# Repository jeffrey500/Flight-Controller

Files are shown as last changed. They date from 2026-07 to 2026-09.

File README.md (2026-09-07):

# PDFS Flight Controller

The purpose of this project is:
1. Create a Modular platform for future drone control projects 
2. Gain experience writing firmware for STM32 embedded systems
3. Become familiar more familiar with Altium and 4-layer PCB routing
4. Add to my goal of making the entire system of a drone (Project Drone Full Stack PDFS)

## Highlights

### [Video of Drone Flying](https://youtu.be/c6FY-opbWkY)

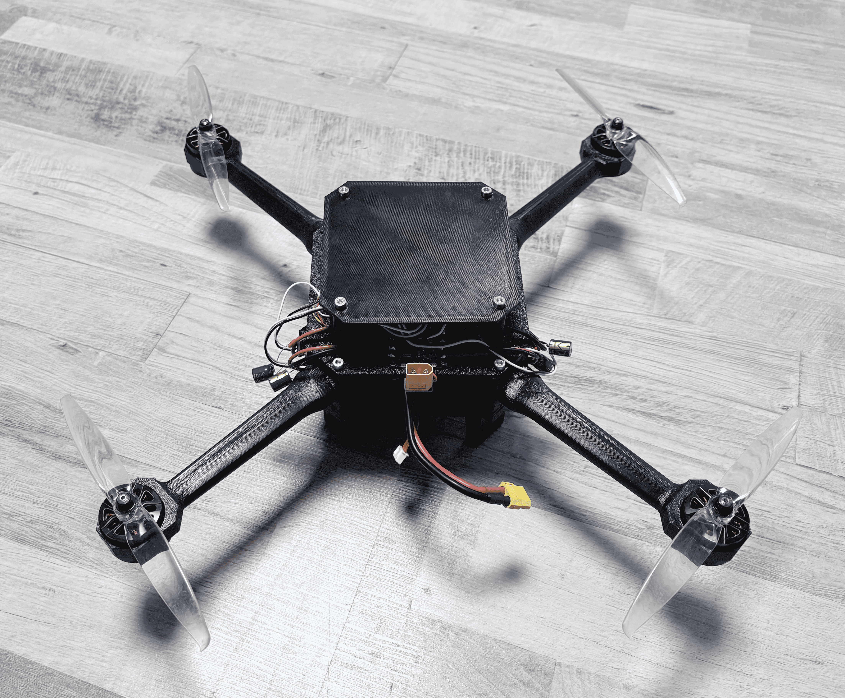
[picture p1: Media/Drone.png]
Board_front
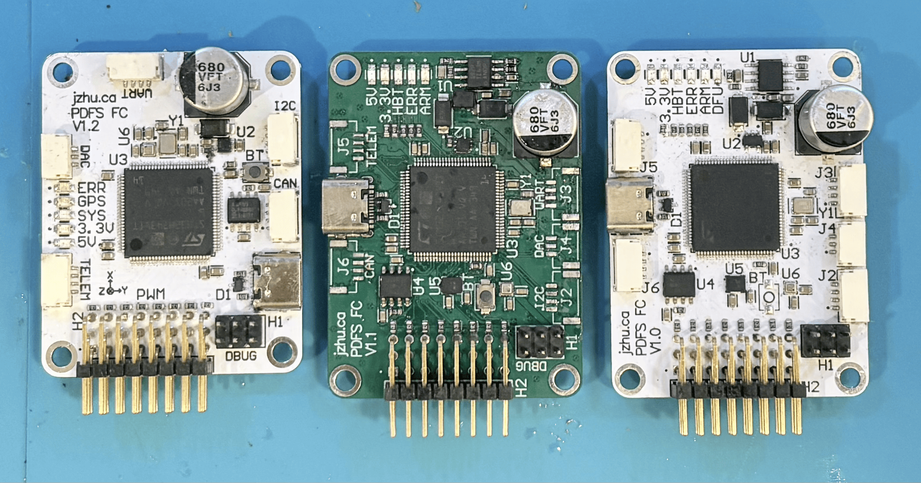
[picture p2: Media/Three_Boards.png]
Board_back
 

### [Firmware](Firmware/README.md)  

- "Angle mode" control
- Deterministic 1kHz control loop
- Cascaded PID Control
- Drivers for IMU and CRSF Radio
- Use of Direct Memory Access and Finite State Machines

### [Hardware](Hardware/README.md)

- STM32H743 Microcontroller
- 4-layer stackup + signal integrity considerations
- Integrated IMU, Barometer, Micro-SD, Buzzer, State LEDs
- Direct power from battery
- SPI, UART, I2C, CAN, USB
- 3D-Printed Drone Frame

### [Arducopter](Arducopter/README.md)

- Hardware Definitions for autonomous flight

## Future Use

Advanced control can be facilitated through connecting a flight computer to the flight controller through UART or SPI.

Altitude and position hold should be implemented in the future with the use of the integrated Barameter and external GPS + Compass.

The use of a digital camera system such as the DJI O3/O4 can be connected through the VTX video port.

## License
[Flight-Controller V1.0](https://github.com/jeffrey500/Flight-Controller) © 2026 by [Jeffrey Zhu](https://jzhu.ca) is licensed under a [Creative Commons Attribution-NonCommercial-ShareAlike 4.0 International License](https://creativecommons.org/licenses/by-nc-sa/4.0/).



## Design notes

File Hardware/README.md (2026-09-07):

# PDFS Flight Controller V1.2

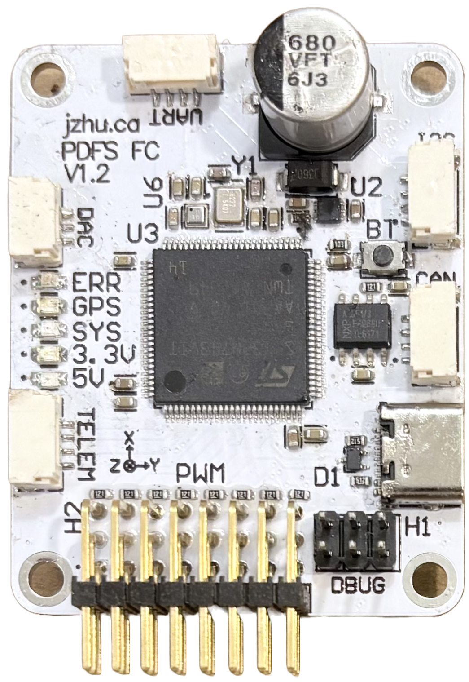
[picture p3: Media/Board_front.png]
Board_front
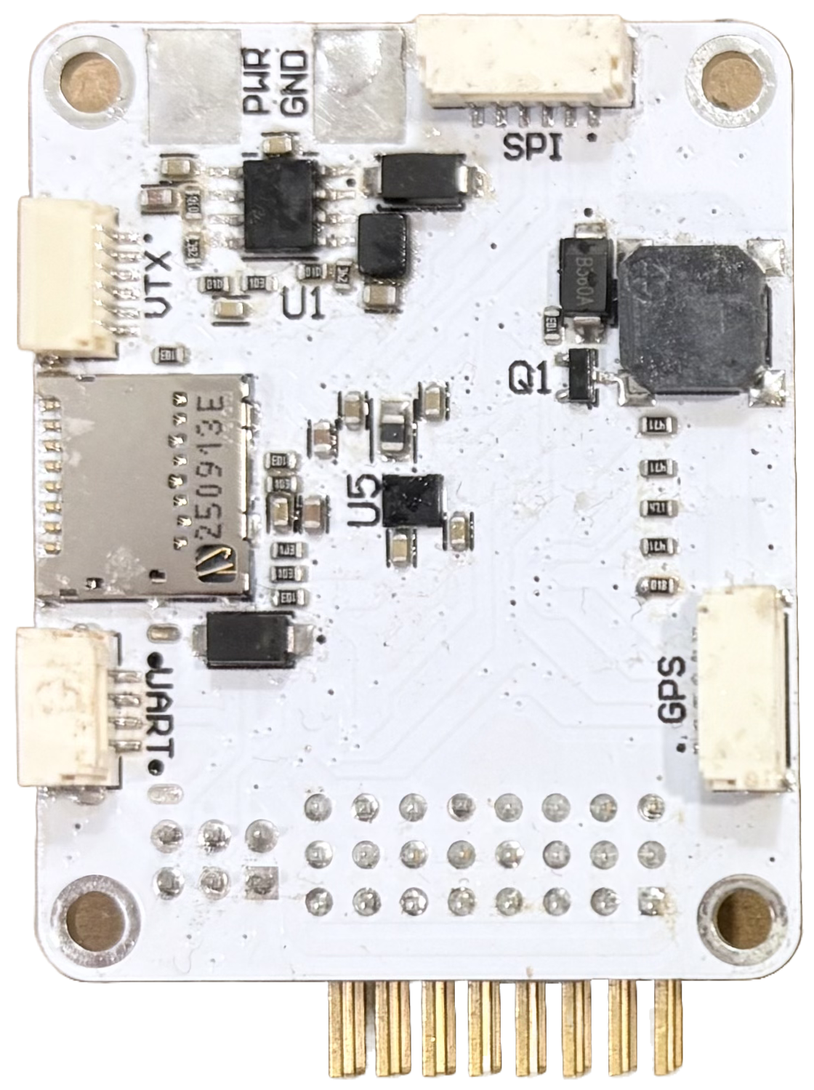
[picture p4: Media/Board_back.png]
Board_back
 

## Improvements from V1.1
1. Complete re-routing of all signal traces for better signal integrity
2. Reduction of total board size
3. Improved silkscreen descriptors of ports and features

## Improvements from V1.0
1. Inductor with higher saturation and max current chosen for Buck Converter
2. Swapped TPS7A2033PDBVR for the TPS74533PQWDRVRQ which has higher max current supply
3. Buzzer moved from PE8 to PA4 (Pin with PWM timer)
4. SD-Card correctly realigned
5. Both 5.1k CC resistors for USB-C attached to ground
6. Removed DFU LED

## Features

| Feature | Capability |
|---|---|
| Processor | STM32H743VIT6 |
| Clock Speed | 480MHz |
| Flash Memory | 2 MB |
| PWM/D-Shot | 8 (4 TIM2 & 4 TIM4) |
| Inertial Measurement Unit | BMI270 |
| Barometer | BMP388 |
| UART (external) | 5 (USART1 USART2 USART3 UART4 USART6) |
| SPI  (external) | 1 (SPI4) |
| CAN bus | 1 |
| Camera Feed | Digital |
| I2C | Row 2, Cell 2 |
| DAC | 1 |
| Power | 5-35V |
| Debugging | Serial Debug |
| Serial | USB-C |
| Logging | Micro-SD Card |

### Timers
The following timers are from the left of the board to the right.

<table>
  <thead>
    <tr>
      <!-- Adjust the colspan values so they add up to 8 total -->
      <th colspan="4">Timer 4</th>
      <th colspan="4">Timer 2</th>
    </tr>
  </thead>
  <tbody>
    <tr>
      <td>Ch1</td>
      <td>Ch2</td>
      <td>Ch3</td>
      <td>Ch4</td>
      <td>Ch1</td>
      <td>Ch2</td>
      <td>Ch3</td>
      <td>Ch4</td>
    </tr>
  </tbody>
</table>

### Connectors
The external connectors for UART, SPI, CAN, and DAC are JST-GH for secure latching connections.  
The PWM/D-Shot uses 2.54mm pitch male header pins in 3 rows of 8 pins.  
An O3 or O4 DJI Air Unit can connect through the 6-pin JST-SH VTX connector.

## CubeMX
The [STM32CubeMX Software](https://www.st.com/en/development-tools/stm32cubemx.html) was used to determine the power and pinout for the STM32H743VIT6.  

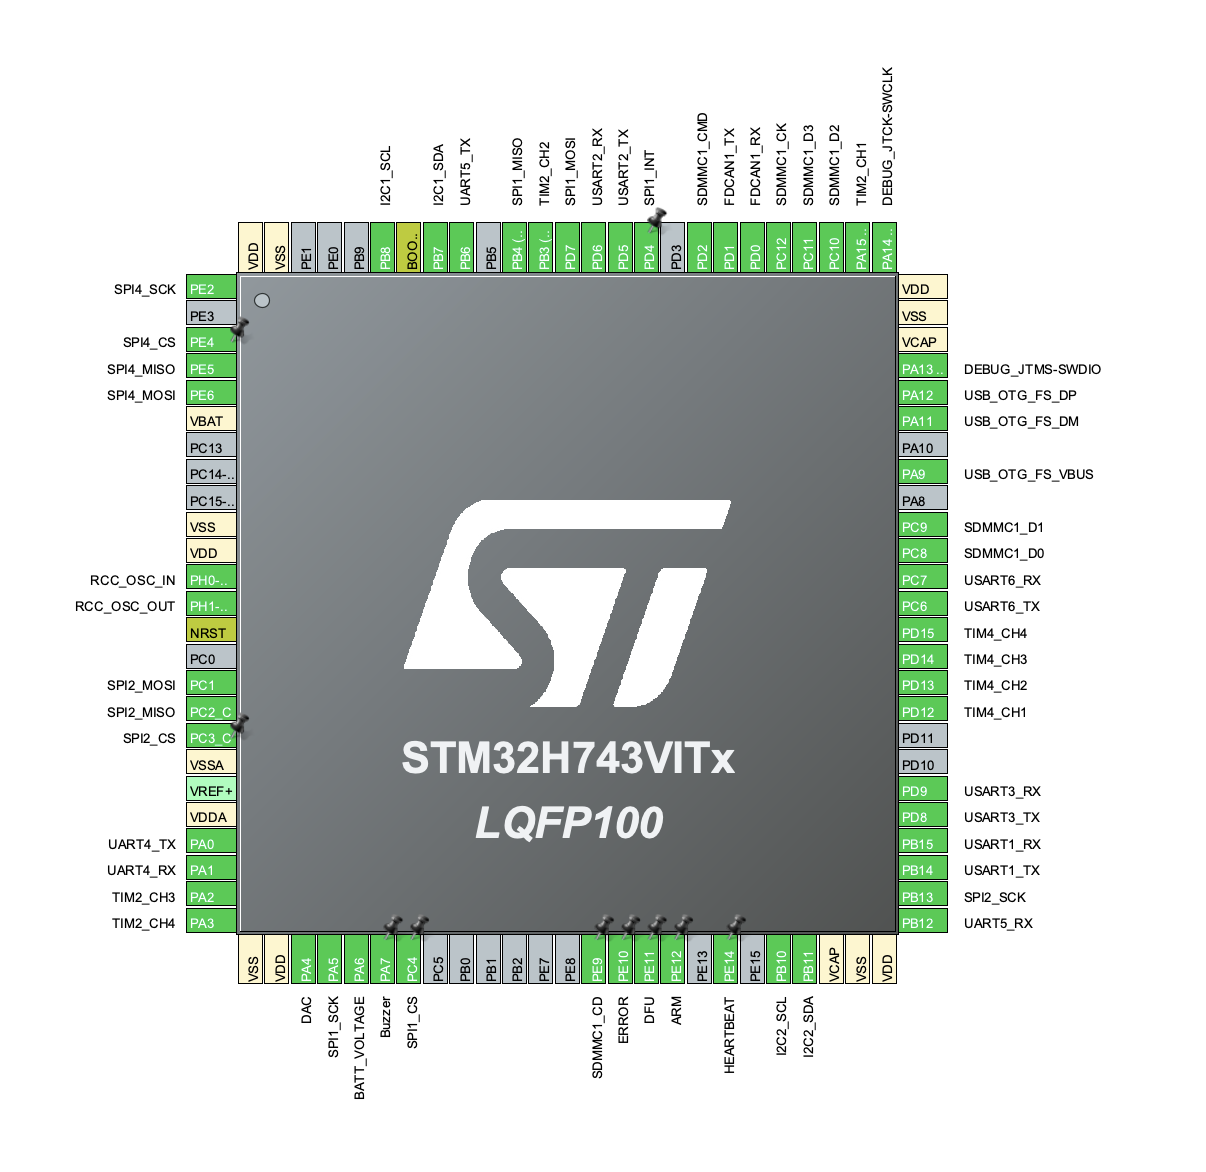
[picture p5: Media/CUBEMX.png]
CUBEMX


## Schematic
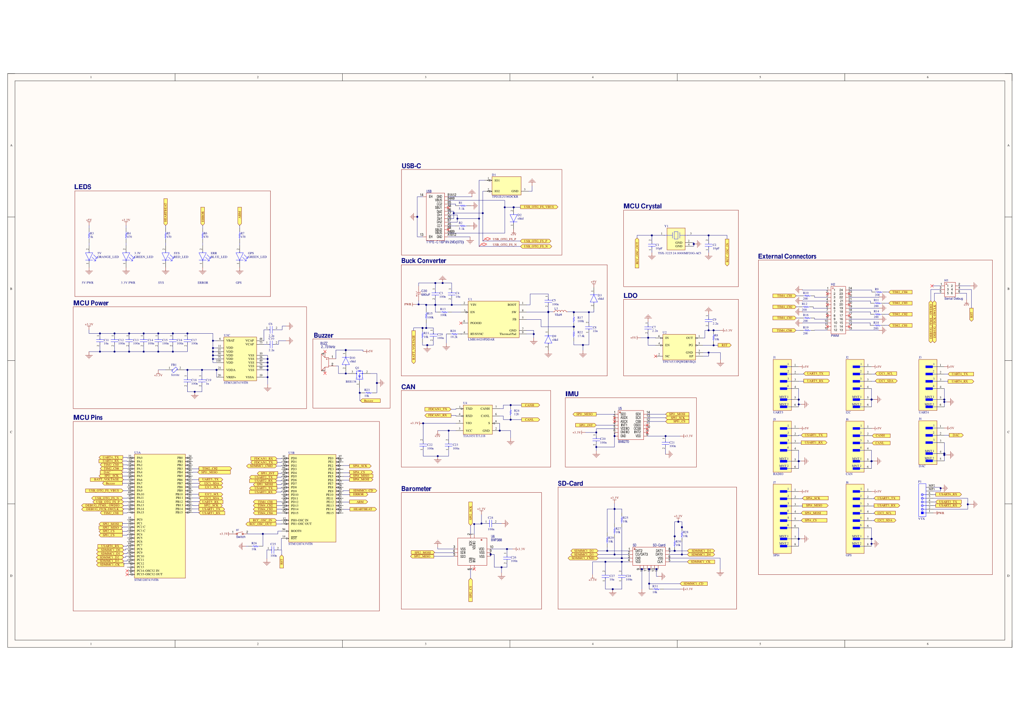
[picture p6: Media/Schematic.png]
Schematic


## Board Stackup
Signal Ground Ground Signal (S-G-G-S) was chosen over Signal Ground Power Signal (S-G-P-S) as both signal layers are shielded from each other by a close ground plane.  
There is also better ground reference vias for signals traveling between the outermost layers.  
Standard copper pour is used for signal layers as well as thorough ground stitching.

| Layer | Purpose |
|---|---|
| 1 | Signal  |
| 2 | Ground  |
| 3 | Ground  |
| 4 | Signal  |

### Top and Bottom signal layers respectively with copper pours
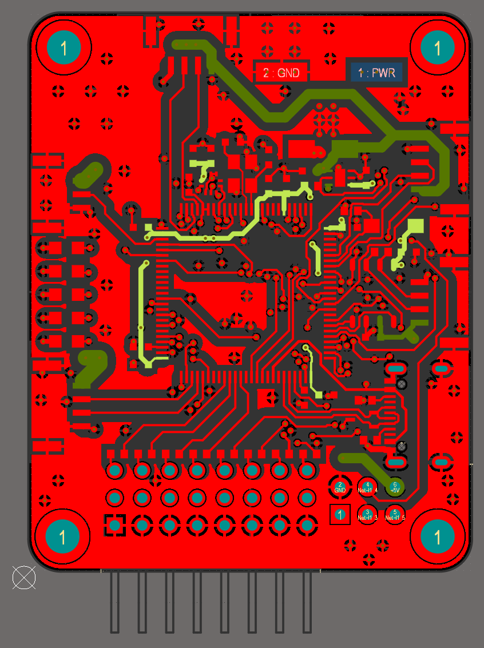
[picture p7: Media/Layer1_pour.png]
Layer1_pour
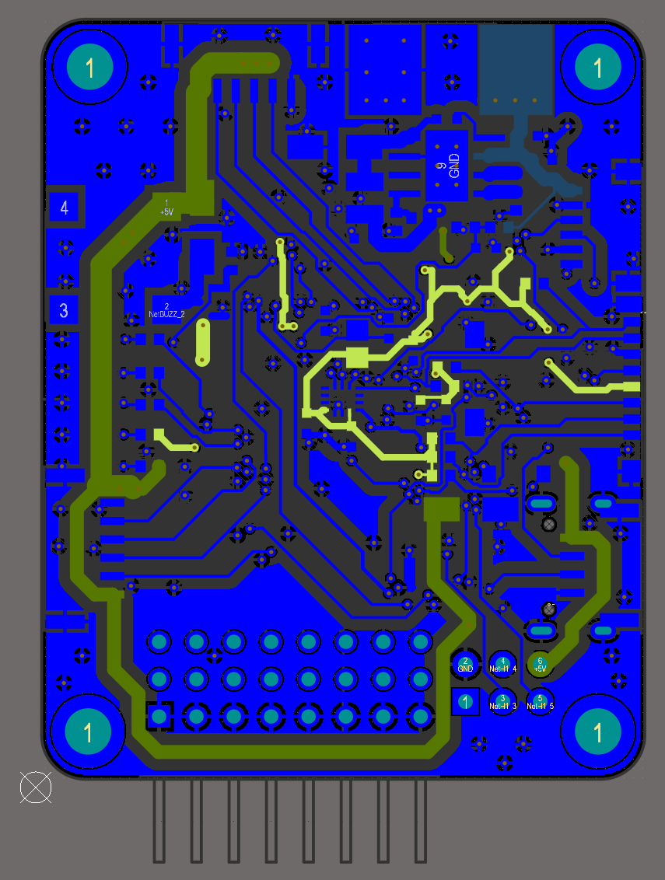
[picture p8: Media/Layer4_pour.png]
Layer4_pour
 

### Internal Ground Plane 2 and 3 respectively   
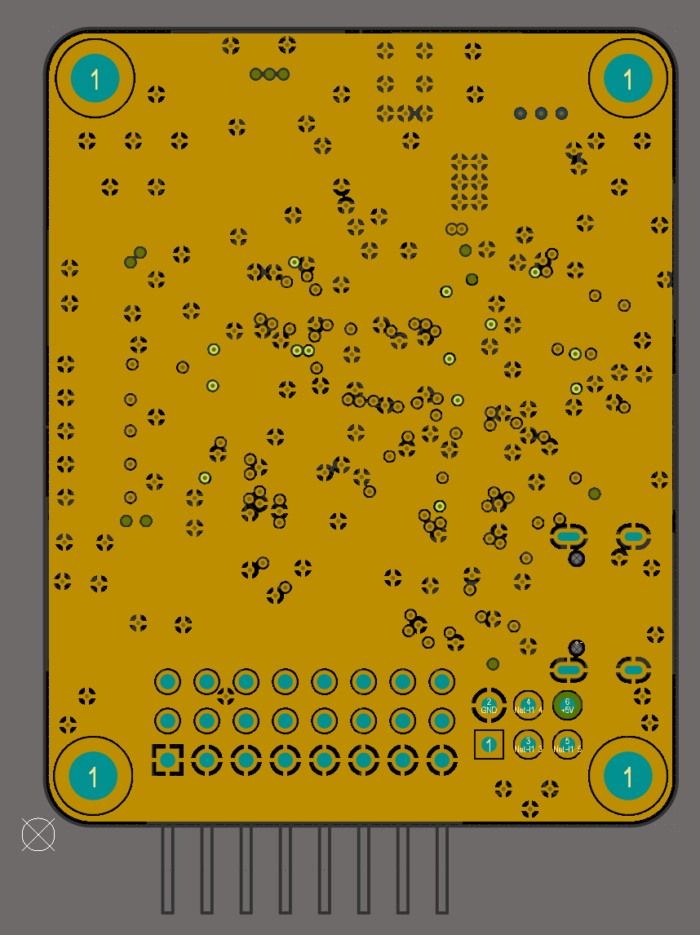
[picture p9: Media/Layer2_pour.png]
Layer1_pour
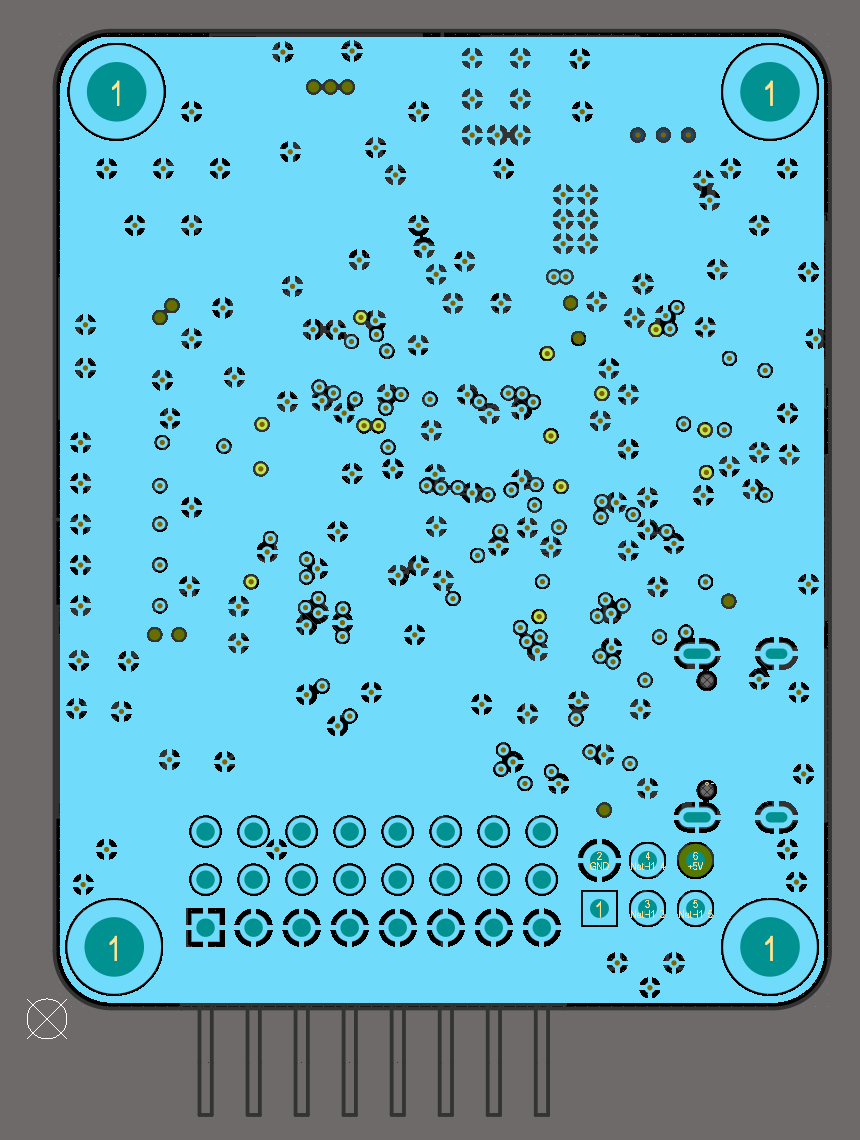
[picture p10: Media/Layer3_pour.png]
Layer4_pour
 

## Routing

### Power
Power is routed through the board using thick PCB traces and many vias. The Board uses a LMR16020 step down simple switcher to get 5V, used to power external peripherals such as radio and GPS.
The TPS74533PQWDRVRQ low dropout regulator is used to further reduce the voltage to 3.3V for the STM32H743 and onboard peripherals.
Such power components were placed in the top right corner to try and isolate the noise they would generate.

### Ground Vias
Anytime a signal traveled between layers, a corresponding ground reference via was placed.

### Signals
Faster or more critical signals were routed first such that they had minimal trace length and travel between layers.   
USB was routed with a differential pair.

Routing Priority: USB, SDMMC, SPI, DAC, CAN, UART, I2C, PWM, GPIO.  

Impedance matching was not done for SDMMC due to a lower speed requirement but length matching (>10mm) was taken into account. 

## Mechanical
Dimensions 41 mm* 51.69 mm. 1.6mm FR4 Board thickness. Four M3 mounting holes on the corners of the board.

## Drone
The Drone frame was fully custonm and designed with [Steven Zhu](https://github.com/zhusteven1010-source/C.A.D-Drone-parts/upload) and was printed using PETG. The drone has a weight around 2kg.

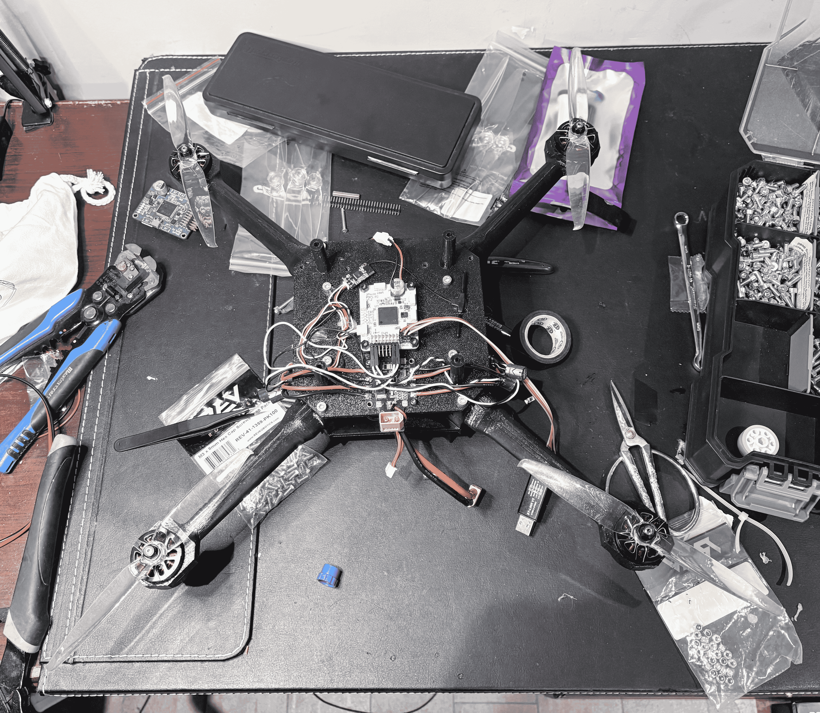
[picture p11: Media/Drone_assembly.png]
Drone_assembly


## License
[Flight-Controller V1.0](https://github.com/jeffrey500/Flight-Controller) © 2026 by [Jeffrey Zhu](https://jzhu.ca) is licensed under a [Creative Commons Attribution-NonCommercial-ShareAlike 4.0 International License](https://creativecommons.org/licenses/by-nc-sa/4.0/).



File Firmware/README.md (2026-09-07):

# Firmware
This firmware was written completely from the ground up in bare-metal C and implements "angle-mode" flight stabilization of symmetric quadcopter X frame. The drone can be externally controlled using any Crossfire Serial Protocol (CRSF) radio connected via the radio JST-GH port (USART1). The drone is stabilized using data from the onboard BMI270 Intertial Measurement Unit (IMU), Radio setpoints, and 2 cascaded control loops.

## System Architecture and Control  
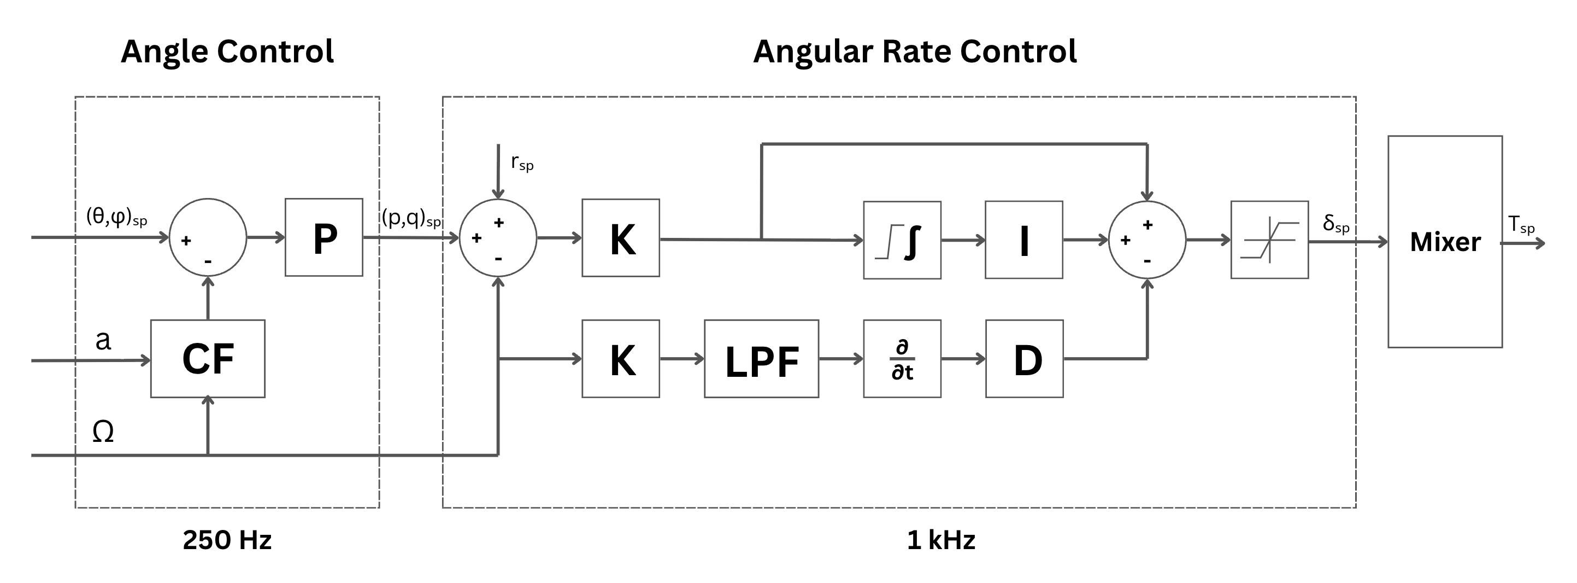
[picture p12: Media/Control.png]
CUBEMX


### Stabilization

The control of the drone is based on a deterministic 1 kHz loop triggered by interrupts on timer 6.

Angle setpoints are provided by the radio through UART and are processed at 250Hz by a complementary filter that combines the accelerometer and the discrete integral of gyro data at a ratio of 98:2, and multiplied by a constant to provide the roll and pitch setpoints.

The angle setpoints–roll and pitch from the angle controller, and yaw from the radio–are fed into a K-PID controller operating at 1 kHz. The controller notably creates the D term using a Low Pass Filter (LPF) from the discrete derivative of the gyro rates. Additionally, the integral and sum of the PID terms are clamped and fed into a mixer that calculates the individual motor throttles.

### Finite State Machine
A finite state machine (FSM) is used to process the radio bytes and store the data into a circular memory buffer, allowing for the assembly of the radio packets to be non-blocking.

### Direct Memory Access
Direct Memory Access (DMA) is used to directly store the radio packets in the circular buffer from the UART connection (RX) and to create the PWM signals required for D-shot300 to drive the motor ESCs (TX). DMA allows for the two functions to work background.

## Notes
The Tim2 and Tim4 are used to generate D-Shot300. The flight controller should be positioned such that the +ive x-axis is facing forward and the +ive z-axis downwards. The following are the mappings for the motor to the channels:  

<table>
  <thead>
    <tr>
      <!-- Adjust the colspan values so they add up to 8 total -->
      <th colspan="1">Timer</th>
      <th colspan="2">Timer 4</th>
      <th colspan="2">Timer 2</th>
    </tr>
  </thead>
  <tbody>
    <tr>
      <td>Channel #</td>
      <td>1</td>
      <td>2</td>
      <td>3</td>
      <td>4</td>
    </tr>
    <tr>
      <td>Motor</td>
      <td>A</td>
      <td>B</td>
      <td>C</td>
      <td>D</td>
    </tr>
  </tbody>
</table>

CUBEMX

## Tuning Procedure
1. Tune the angle rate controllers
   1. Keep D and I at zero and vary the K value until you have slight oscillations
   2. Start with a small D value and increase until audible or visible vibration of the motors
   3. Add a small I term until you remove constant error
2. Tune the angle controllers until you are comfortable with the angle command by your remote

## Next Steps
- Altitude hold using onboard barometer
- Position hold using GPS (look into quaternions)
- FSM for state of the drone (armed vs not)
- Integrate onboard SD card
- Integrate onboard buzzer and leds for flight state

## Helpful Documents
https://github.com/betaflight/betaflight
https://github.com/ArduPilot/ardupilot/tree/master/ArduCopter
https://docs.px4.io/main/en/flight_stack/controller_diagrams  
https://betaflight.com/docs/development/API/Dshot   
https://github.com/tbs-fpv/tbs-crsf-spec/blob/main/crsf.md  
https://www.bosch-sensortec.com/media/boschsensortec/downloads/datasheets/bst-bmi270-ds000.pdf

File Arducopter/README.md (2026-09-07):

## Arducopter

The Ardupilot bootloader and firmware can be flashed by using an ST-LINK and Serial Debug pins at the bottom right of the board.  

See the attached [Binary Bootloader File](/Ardupilot%20Firmware/AP_Bootloader.bin) and [Binary Firmware File](/Ardupilot%20Firmware/AP_Bootloader.bin).  
See the attached hardware definition files [hwdef.dat](/Ardupilot%20Firmware/hwdef.dat) and [hwdef-bl.dat](/Ardupilot%20Firmware/hwdef-bl.dat) that can be built using the [Ardupilot Repository](https://github.com/Ardupilot/ardupilot).

## Ardupilot Build
```bash
cd ardupilot/
./waf clean
./waf configure --board MyCustomFC
./waf copter
```

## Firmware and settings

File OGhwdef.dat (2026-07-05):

# hw definition file for processing by chibios_hwdef.py
# for FMUv3 hardware (ie. for Pixhawk1, Pixhawk2 cube, XUAV2.1 etc)

# This hwdef.dat file contains a lot of comments so it can act as a
# reference for developers adding new boards.

# The hwdef.dat file defines all the hardware peripherals and pins for
# a port of ArduPilot to a board using the ChibiOS HAL. You should be
# able to write the hwdef.dat file for a new board with just the
# schematic for the board.

# This file is processed by chibios_hwdef.py to create hwdef.h for
# this board. You may find it useful to run chibios_hwdef.py manually
# when building this file for a new board. The resulting hwdef.h file
# is formatted to make it quite readable. It is strongly suggested
# that you read the resulting hwdef.h file when porting to a new board
# to make sure it has resulted in what you want.

# You should read this file in conjunction with the schematic for your
# board, the datasheet for the MCU for your board and the python
# tables file that we have extracted from the datasheet for your
# MCU. The python tables file is particularly important, so if you
# haven't seen it before go and look at it now. For the STM32F427 it
# it called STM32F427xx.py and it is in the hwdef/script/ directory
# inside the HAL_ChibiOS directory. That file tells you what each pin
# can do (the alternate functions table) and what DMA channels can be
# used for each peripheral type. The alternative functions table is
# particularly useful when doing a new hwdef.dat file as you can work
# out peripheral numbers given a port/pin name.

# We need to start off by saying what main CPU is on the board. There
# are two CPU identifiers that you need to specify. The first is the
# ChibiOS MCU type. So far we only support STM32F4xx for all STM32F4
# board types. In the future we will add F7 and other MCU types
# The second string needs to match the name of a config file in the
# libraries/AP_HAL_ChibiOS/hwdef/script directory. In this case we are
# using a F427 MCU, so we select STM32F427xx to match the
# STM32F427xx.py file in the script directory. If you are supporting a
# board type that doesn't have a python hardware database file yet
# then you will need to create one. There are scripts in the scripts
# directory to help with that by parsing the STM32 datasheets to
# extract the required DMA and alternate function tables.

# MCU class and specific type
MCU STM32H7xx STM32H743xx

# Now we need to specify the APJ_BOARD_ID. This is the ID that the
# bootloader presents to GCS software so it knows if this firmware is
# suitable for the board. Please see
# https://github.com/ArduPilot/Bootloader/blob/master/hw_config.h for
# a list of current board IDs. If you add a new board type then please
# get it added to that repository so we don't get conflicts.

# Note that APJ is "ArduPilot JSON Firmware Format".

# board ID. See Tools/AP_Bootloader/board_types.txt
define HAL_BOARD_NAME "MY_CUSTOM_FC"
env APJ_BOARD_ID 1054

# Now you need to say what crystal frequency you have for this
# board. All of the clocks are scaled against this. Typical values are
# 24000000 or 8000000.

# crystal frequency
OSCILLATOR_HZ 24000000

# On some boards you will need to also set the various PLL values. See
# the defaults in common/mcuconf.h, and use the define mechanism
# explained later in this file to override values suitable for your
# board. Refer to your MCU datasheet or examples from supported boards
# in ChibiOS for the right values.

# This is the STM32 timer that ChibiOS will use for the low level
# driver. This must be a 32 bit timer. We currently only support
# timers 2, 3, 4, 5 and 21. See hal_st_lld.c in ChibiOS for details.

# ChibiOS system timer
STM32_ST_USE_TIMER 5

# Now the size of flash in kilobytes, for creating the ld.script.

# flash size
FLASH_SIZE_KB 2048

# Now define which UART is used for printf(). We rarely use printf()
# in ChibiOS, so this is really only for debugging very early startup
# in drivers.

# Serial port for stdout. This is optional. If you leave it out then
# output from printf() lines will go to the ArduPilot console, which is the
# first UART in the SERIAL_ORDER list.  But note that some startup code
# runs before USB is set up.
# The value for STDOUT_SERIAL is a serial device name, and must be for a
# serial device for which pins are defined in this file. For example, SD7
# is for UART7 (SD7 == "serial device 7" in ChibiOS).
#STDOUT_SERIAL SD7
#STDOUT_BAUDRATE 57600

# Now the USB setup, if you have USB. All of these settings are
# option, and the ones below are the defaults. It ends up creating a
# USB ID on Linux like this:
# /dev/serial/by-id/usb-ArduPilot_fmuv3_3E0031000B51353233343932-if00
# If creating a board for a RTF vehicle you may wish to customise these.

# USB setup
USB_VEN
USB_STRING_MANUFACTURER "Custom"
USB_STRING_PRODUCT "MY_CUSTOM_FC"

# Now define the order that I2C buses are presented in the hal.i2c API
# in ArduPilot. For historical reasons inherited from HAL_PX4 the
# 'external' I2C bus should be bus 1 in hal.i2c, and internal I2C bus
# should be bus 0. On fmuv3 the STM32 I2C1 is our external bus and
# I2C2 is our internal bus, so we need to setup the order as I2C2
# followed by I2C1 in order to achieve the conventional order that
# drivers expect.

# order of I2C buses
I2C_ORDER I2C2 I2C1

# Now the serial ordering. These map to the SERIALn_ parameter numbers
# If you use a shorter list then HAL_Empty::UARTDriver
# objects are substituted for later UARTs, or you can leave a gap by
# listing one or more of the uarts as EMPTY.

# The normal usage of this ordering is:
# 1) SERIAL0: console (primary mavlink, usually USB)
# 2) SERIAL1: telem1
# 3) SERIAL2: telem2
# 4) SERIAL3: primary GPS
# 5) SERIAL4: GPS2
# 6) SERIAL5: extra UART (usually RTOS debug console)

# order of UARTs (and USB)
SERIAL_ORDER OTG1 USART2 USART3 UART4 UART8 UART7

# If the board has an IOMCU connected via a UART then this defines the
# UART to talk to that MCU. Leave it out for boards with no IOMCU.

# UART for IOMCU
IOMCU_UART USART6

# Now we start on the pin definitions. Every pin used by ArduPilot
# needs to be in this file. The pins in this file can be defined in any order.

# The format is P+port+pin. So PC4 is portC pin4.
# For every pin the second column is the label. If this is a
# peripheral that has an alternate function defined in the STM32
# datasheet then the label must be the name of that alternative
# function. The names are looked up in the python database for this
# MCU. Please see STM32F427xx.py for the F427 database. That database
# is used to automatically fill in the alternative function (and later
# for the DMA channels).

# The third column is the peripheral type. This must be one of the
# following: UARTn, USARTn, OTGn, SPIn, I2Cn, ADCn, TIMn, SWD, SDIO,
# INPUT, OUTPUT, CS.

# The fourth and later columns are for modifiers on the pin. The
# possible modifiers are:
# pin speed: SPEED_VERYLOW, SPEED_LOW, SPEED_MEDIUM, SPEED_HIGH
# pullup: PULLUP, PULLDOWN, FLOATING
# out type: OPENDRAIN, PUSHPULL
# default value: LOW, HIGH

# Additionally, each class of pin peripheral can have extra modifiers
# suitable for that pin type. For example, for an OUTPUT you can map
# it to a GPIO number in hal.gpio using the GPIO(n) modifier. For ADC
# inputs you can apply a scaling factor (to bring it to unit volts)
# using the SCALE(x) modifier. See the examples below for more
# modifiers, or read the python code in chibios_hwdef.py.

# Now we define UART4 which is for the GPS. Be careful
# of the difference between USART and UART. Check the STM32F427xx.py
# if unsure which it is. For a UART we need to specify at least TX and
# RX pins.

# UART4 serial GPS
PA0 UART4_TX UART4
PA1 UART4_RX UART4

# Now define the primary battery connectors. The labels we choose here
# are used to create defines for pins in the various drivers, so
# choose names that match existing board setups where possible. Here
# we define two pins PA2 and PA3 for voltage and current sensing, with
# a scale factor of 1.0 and connected on ADC1. The pin number this
# maps to in hal.adc is automatically determined using the datasheet
# tables in STM32F427xx.py.

PA2 BATT_VOLTAGE_SENS ADC1 SCALE(1)
PA3 BATT_CURRENT_SENS ADC1 SCALE(1)

# Now the VDD sense pin. This is used to sense primary board voltage.
PA4 VDD_5V_SENS ADC1 SCALE(2)

# Now the first SPI bus. At minimum you need SCK, MISO and MOSI pin
definitions. You can add speed modifiers if you want them, otherwise
the defaults for the peripheral class are used.

PA5 SPI1_SCK SPI1
PA6 SPI1_MISO SPI1
PA7 SPI1_MOSI SPI1

# This defines an output pin which will default to output LOW. It is a
# pin that enables peripheral power on this board.

PA8 nVDD_5V_PERIPH_EN OUTPUT LOW

# This is the pin that senses USB being connected. It is an input pin
# setup as OPENDRAIN.
PA9 VBUS INPUT OPENDRAIN
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

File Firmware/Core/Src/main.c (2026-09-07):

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
/* Includes ------------------------------------------------------------------*/
#include "main.h"
#include "usb_device.h"

/* USER CODE BEGIN Includes */
#include <stdint.h>
#include <string.h>
#include <sys/types.h>
#include "imu.h"
#include "radio.h"
#include "mixer.h"
#include "pid.h"
#include "dshot.h"
#include "attitude.h"

/* USER CODE END Includes */

ADC_HandleTypeDef hadc1;

DAC_HandleTypeDef hdac1;

FDCAN_HandleTypeDef hfdcan1;

I2C_HandleTypeDef hi2c1;
I2C_HandleTypeDef hi2c2;

SD_HandleTypeDef hsd1;

SPI_HandleTypeDef hspi1;
SPI_HandleTypeDef hspi2;
SPI_HandleTypeDef hspi4;

TIM_HandleTypeDef htim2;
TIM_HandleTypeDef htim3;
TIM_HandleTypeDef htim4;
TIM_HandleTypeDef htim6;
DMA_HandleTypeDef hdma_tim2_ch1;
DMA_HandleTypeDef hdma_tim2_ch2;
DMA_HandleTypeDef hdma_tim2_ch3;
DMA_HandleTypeDef hdma_tim2_ch4;
DMA_HandleTypeDef hdma_tim4_ch1;
DMA_HandleTypeDef hdma_tim4_ch2;

UART_HandleTypeDef huart4;
UART_HandleTypeDef huart5;
UART_HandleTypeDef huart1;
UART_HandleTypeDef huart2;
UART_HandleTypeDef huart3;
UART_HandleTypeDef huart6;
DMA_HandleTypeDef hdma_usart1_rx;

/* USER CODE BEGIN PV */

// 1kHz loop variables
volatile uint8_t loop_ready = 0;
int counter = 0;

// DMA buffer for Radio.
#define RADIO_BUFFER_SIZE 512

__attribute__((section(".ram_d2"), aligned(32)))
uint8_t rx_buffer[RADIO_BUFFER_SIZE];

uint16_t rx_head = 0;
uint16_t rx_tail = 0;

uint16_t last_radio_transmission = 0;

// Data
RC_Channels current_channel_data;
IMU_data current_imu_data;
Attitude_data current_attitude_data;

// Control loop variables
PID_Controller angle_pid_roll;
PID_Controller angle_pid_pitch;
PID_Controller pid_roll;
PID_Controller pid_pitch;
PID_Controller pid_yaw;

float angle_pid_output_roll;
float angle_pid_output_pitch;
float angular_pid_output_roll;
float angular_pid_output_pitch;
float angular_pid_output_yaw;

volatile uint32_t dma_count = 0;
volatile uint32_t radio_bytes = 0;
volatile uint32_t radio_valid_frames = 0;
volatile uint32_t radio_rc_frames = 0;
volatile uint32_t radio_crc_errors = 0;
volatile uint32_t radio_dma_restarts = 0;

/* USER CODE END PV */

void SystemClock_Config(void);
void PeriphCommonClock_Config(void);
static void MPU_Config(void);
static void MX_GPIO_Init(void);
static void MX_DMA_Init(void);
static void MX_FDCAN1_Init(void);
static void MX_I2C1_Init(void);
static void MX_SDMMC1_SD_Init(void);
static void MX_SPI1_Init(void);
static void MX_SPI2_Init(void);
static void MX_TIM2_Init(void);
static void MX_ADC1_Init(void);
static void MX_I2C2_Init(void);
static void MX_TIM4_Init(void);
static void MX_UART4_Init(void);
static void MX_UART5_Init(void);
static void MX_USART1_UART_Init(void);
static void MX_USART2_UART_Init(void);
static void MX_USART3_UART_Init(void);
static void MX_DAC1_Init(void);
static void MX_SPI4_Init(void);
static void MX_USART6_UART_Init(void);
static void MX_TIM3_Init(void);
static void MX_TIM6_Init(void);
/**
  * @brief  The application entry point.
  * @retval int
  */
int main(void)
{

  /* MPU Configuration--------------------------------------------------------*/
  MPU_Config();

  /* MCU Configuration--------------------------------------------------------*/

  /* Reset of all peripherals, Initializes the Flash interface and the Systick. */
  HAL_Init();

  /* Configure the system clock */
  SystemClock_Config();

  /* Configure the peripherals common clocks */
  PeriphCommonClock_Config();

  /* Initialize all configured peripherals */
  MX_GPIO_Init();
  MX_DMA_Init();
  MX_FDCAN1_Init();
  MX_I2C1_Init();
  // MX_SDMMC1_SD_Init();
  MX_SPI1_Init();
  MX_SPI2_Init();
  MX_TIM2_Init();
  MX_USB_DEVICE_Init();
  MX_ADC1_Init();
  MX_I2C2_Init();
  MX_TIM4_Init();
  MX_UART4_Init();
  MX_UART5_Init();
  MX_USART1_UART_Init();
  MX_USART2_UART_Init();
  MX_USART3_UART_Init();
  MX_DAC1_Init();
  MX_SPI4_Init();
  MX_USART6_UART_Init();
  MX_TIM3_Init();
  MX_TIM6_Init();
  /* USER CODE BEGIN 2 */

  // 1kHz loop timer
  HAL_TIM_Base_Start_IT(&htim6);

  // Ensure IMU start proper, else ERROR light and lock
  if(IMU_Init() == false){
    HAL_GPIO_WritePin(ERROR_GPIO_Port, ERROR_Pin, GPIO_PIN_SET);
    while (1) {}
  }

  // Initalize PID for Angle Control
  PID_Init(&angle_pid_roll, 0.004f, 0, 5.0f, 0, 0, 0, 200.0f);
  PID_Init(&angle_pid_pitch, 0.004f, 0, 5.0f, 0, 0, 0, 200.0f);

  // Initalize PID for Angular Rate Control
  PID_Init(&pid_roll, 0.001f, 0.3f, 4.0f, 0.0f, 0.002f, 100.0f, 300.0f);
  PID_Init(&pid_pitch, 0.001f, 0.3f, 4.0f, 0.0f, 0.002f, 100.0f, 300.0f);
  PID_Init(&pid_yaw, 0.001f, 0.3f, 8.0f, 0.0f, 0.003f, 100.0f, 300.0f);

  // Clear any stale error flags before arming DMA reception
  __HAL_UART_CLEAR_OREFLAG(&huart1);
  __HAL_UART_CLEAR_FEFLAG(&huart1);
  __HAL_UART_CLEAR_NEFLAG(&huart1);
  __HAL_UART_CLEAR_PEFLAG(&huart1);

  memset(rx_buffer, 0xAA, RADIO_BUFFER_SIZE);   // known sentinel, not 0x00 or 0xFF for debugging
  rx_head = 0;
  rx_tail = 0;

  // Start Radio circular DMA
  if (HAL_UART_Receive_DMA(&huart1, rx_buffer, RADIO_BUFFER_SIZE) != HAL_OK)
  {
    HAL_GPIO_WritePin(ERROR_GPIO_Port, ERROR_Pin, GPIO_PIN_SET);
    while (1) {} // trap here so you know immediately if arming failed
  }

  HAL_GPIO_WritePin(HEARTBEAT_GPIO_Port, HEARTBEAT_Pin,GPIO_PIN_SET);

  /* USER CODE END 2 */

  /* Infinite loop */
  /* USER CODE BEGIN WHILE */
  while (1)
  {
    /* USER CODE END WHILE */

    /* USER CODE BEGIN 3 */

    if (loop_ready){

      loop_ready = 0;
      counter++;
      last_radio_transmission++;

      // Pulse hearbeat at 0.5Hz
      if (counter >= 1000){
        counter = 0;
        HAL_GPIO_TogglePin(HEARTBEAT_GPIO_Port, HEARTBEAT_Pin);
      }

      // Pulse hearbeat at 0.5Hz
      if (counter >= 1000){
        counter = 0;
        HAL_GPIO_TogglePin(HEARTBEAT_GPIO_Port, HEARTBEAT_Pin);
      }

      dma_count = __HAL_DMA_GET_COUNTER(huart1.hdmarx);

      rx_head = RADIO_BUFFER_SIZE - dma_count;

      if (rx_head >= RADIO_BUFFER_SIZE)
      {
          rx_head = 0;
      }

      while (rx_tail != rx_head)
      {
          radio_bytes++;

          Radio_ProcessByte(rx_buffer[rx_tail]);

          rx_tail++;

          if (rx_tail >= RADIO_BUFFER_SIZE)
          {
              rx_tail = 0;
          }
      }


      // Check if there is new complete channel data
      if (Radio_GetChannels(&current_channel_data)){
        last_radio_transmission = 0;
      }

      //Add Radio failsafe here later

      // Get IMU Data
      IMU_Read(&current_imu_data);

      // 250 Hz loop for angle control
      if ((counter-1)%4 == 0){

        // Calculate attitude data
        Update_Attitude(0.98f, 0.004, &current_imu_data, &current_attitude_data);

        // Attitude Angle Control 
        angle_pid_output_roll = PID_Generate(&angle_pid_roll, channel_to_angle(current_channel_data.roll, 20), current_attitude_data.roll);
        angle_pid_output_pitch = PID_Generate(&angle_pid_pitch, channel_to_angle(current_channel_data.pitch, 20), current_attitude_data.pitch);
      }

      // Roll Pitch Yaw Angular Rate Control
      angular_pid_output_roll = PID_Generate(&pid_roll, angle_pid_output_roll, current_imu_data.gyro_x);
      angular_pid_output_pitch = PID_Generate(&pid_pitch, angle_pid_output_pitch, current_imu_data.gyro_y);
      angular_pid_output_yaw = PID_Generate(&pid_yaw, channel_to_angular_rate(current_channel_data.yaw, 90.0f), current_imu_data.gyro_z);

      // Update motor outputs via mixer
      if (current_channel_data.arm <= 700 || last_radio_transmission > 200){
        Mixer(0, angular_pid_output_roll, angular_pid_output_pitch, angular_pid_output_yaw, 100);
        // Turn off the arm LED
        HAL_GPIO_WritePin(ARM_GPIO_Port, ARM_Pin, GPIO_PIN_RESET);

        // Keep integrals zero while disarmed
        pid_roll.integral = pid_pitch.integral = pid_yaw.integral = 0.0f;
        angle_pid_roll.integral = angle_pid_pitch.integral = 0.0f;

        // Prevent overflow
        last_radio_transmission = 500;
      } else {
        Mixer(current_channel_data.throttle, angular_pid_output_roll, angular_pid_output_pitch, angular_pid_output_yaw, 50);
        // Turn on the arm LED
        HAL_GPIO_WritePin(ARM_GPIO_Port, ARM_Pin, GPIO_PIN_SET);
      }

      // Send motor outputs via dshot
      DSHOT_Update();

    }

  }
  /* USER CODE END 3 */
}

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
/* USER CODE BEGIN 4 */

void HAL_TIM_PeriodElapsedCallback(TIM_HandleTypeDef *htim){
  if (htim->Instance == TIM6) {
    loop_ready = 1;
  }
}

// Any UART error raised while a DMA reception is active makes the HAL tear the
// transfer down for good - see the "any error occurs in DMA mode reception"
// branch of HAL_UART_IRQHandler(). Framing and noise errors are routine on a
// 420 kbaud CRSF line whenever the receiver boots, browns out or is unplugged,
// so restart the stream instead of losing the radio permanently.
void HAL_UART_ErrorCallback(UART_HandleTypeDef *huart)
{
  if (huart->Instance != USART1) {
    return;
  }

  radio_dma_restarts++;

  __HAL_UART_CLEAR_OREFLAG(huart);
  __HAL_UART_CLEAR_FEFLAG(huart);
  __HAL_UART_CLEAR_NEFLAG(huart);
  __HAL_UART_CLEAR_PEFLAG(huart);
  huart->ErrorCode = HAL_UART_ERROR_NONE;

  // The abort reset NDTR, so the read pointer has to follow it back to 0.
  rx_head = 0;
  rx_tail = 0;

  HAL_UART_Receive_DMA(huart, rx_buffer, RADIO_BUFFER_SIZE);
}

/* USER CODE END 4 */

 /* MPU Configuration */

void MPU_Config(void)
{
  MPU_Region_InitTypeDef MPU_InitStruct = {0};

  /* Disables the MPU */
  HAL_MPU_Disable();

  /** Initializes and configures the Region and the memory to be protected
  */
  MPU_InitStruct.Enable = MPU_REGION_ENABLE;
  MPU_InitStruct.Number = MPU_REGION_NUMBER0;
  MPU_InitStruct.BaseAddress = 0x0;
  MPU_InitStruct.Size = MPU_REGION_SIZE_4GB;
  MPU_InitStruct.SubRegionDisable = 0x87;
  MPU_InitStruct.TypeExtField = MPU_TEX_LEVEL0;
  MPU_InitStruct.AccessPermission = MPU_REGION_NO_ACCESS;
  MPU_InitStruct.DisableExec = MPU_INSTRUCTION_ACCESS_DISABLE;
  MPU_InitStruct.IsShareable = MPU_ACCESS_SHAREABLE;
  MPU_InitStruct.IsCacheable = MPU_ACCESS_NOT_CACHEABLE;
  MPU_InitStruct.IsBufferable = MPU_ACCESS_NOT_BUFFERABLE;

  HAL_MPU_ConfigRegion(&MPU_InitStruct);
  /* Enables the MPU */
  HAL_MPU_Enable(MPU_PRIVILEGED_DEFAULT);

}

/**
  * @brief  This function is executed in case of error occurrence.
  * @retval None
  */
void Error_Handler(void)
{
  /* USER CODE BEGIN Error_Handler_Debug */
  /* User can add his own implementation to report the HAL error return state */
  __disable_irq();
  while (1)
  {
  }
  /* USER CODE END Error_Handler_Debug */
}
#ifdef USE_FULL_ASSERT
/**
  * @brief  Reports the name of the source file and the source line number
  *         where the assert_param error has occurred.
  * @param  file: pointer to the source file name
  * @param  line: assert_param error line source number
  * @retval None
  */
void assert_failed(uint8_t *file, uint32_t line)
{
  /* USER CODE BEGIN 6 */
  /* User can add his own implementation to report the file name and line number,
     ex: printf("Wrong parameters value: file %s on line %d\r\n", file, line) */
  /* USER CODE END 6 */
}
#endif /* USE_FULL_ASSERT */

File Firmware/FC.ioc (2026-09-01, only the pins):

Mcu.UserName=STM32H743VITx
PA0.Signal=UART4_TX
PA1.Signal=UART4_RX
PA11.Signal=USB_OTG_FS_DM
PA12.Signal=USB_OTG_FS_DP
PA2.Signal=S_TIM2_CH3
PA3.Signal=S_TIM2_CH4
PA4.GPIO_Label=DAC
PA4.Signal=COMP_DAC11_group
PA5.Signal=SPI1_SCK
PA6.GPIO_Label=BATT_VOLTAGE
PA6.Signal=ADCx_INP3
PA7.GPIO_Label=Buzzer
PA7.Signal=S_TIM3_CH2
PA9.Signal=USB_OTG_FS_VBUS
PB10.Signal=I2C2_SCL
PB11.Signal=I2C2_SDA
PB12.Signal=UART5_RX
PB13.Signal=SPI2_SCK
PB14.Signal=USART1_TX
PB15.Signal=USART1_RX
PB6.Signal=UART5_TX
PB7.Signal=I2C1_SDA
PB8.Signal=I2C1_SCL
PC1.Signal=SPI2_MOSI
PC10.Signal=SDMMC1_D2
PC11.Signal=SDMMC1_D3
PC12.Signal=SDMMC1_CK
PC2_C.Signal=SPI2_MISO
PC3_C.GPIO_Label=SPI2_CS
PC3_C.Signal=GPIO_Output
PC4.GPIO_Label=SPI1_CS
PC4.Signal=GPIO_Output
PC6.Signal=USART6_TX
PC7.Signal=USART6_RX
PC8.Signal=SDMMC1_D0
PC9.Signal=SDMMC1_D1
PD0.Signal=FDCAN1_RX
PD1.Signal=FDCAN1_TX
PD12.Signal=S_TIM4_CH1
PD13.Signal=S_TIM4_CH2
PD14.Signal=S_TIM4_CH3
PD15.Signal=S_TIM4_CH4
PD2.Signal=SDMMC1_CMD
PD4.GPIO_Label=SPI1_INT
PD4.Signal=GPIO_Output
PD5.Signal=USART2_TX
PD6.Signal=USART2_RX
PD7.Signal=SPI1_MOSI
PD8.Signal=USART3_TX
PD9.Signal=USART3_RX
PE10.GPIO_Label=ERROR
PE10.Signal=GPIO_Output
PE11.GPIO_Label=DFU
PE11.Signal=GPIO_Output
PE12.GPIO_Label=ARM
PE12.Signal=GPIO_Output
PE14.GPIO_Label=HEARTBEAT
PE14.Signal=GPIO_Output
PE2.Signal=SPI4_SCK
PE4.GPIO_Label=SPI4_CS
PE4.Signal=GPIO_Output
PE5.Signal=SPI4_MISO
PE6.Signal=SPI4_MOSI
PE9.GPIO_Label=SDMMC1_CD
PE9.Signal=GPIO_Input

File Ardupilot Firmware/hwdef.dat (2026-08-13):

# MCU class and specific type
MCU STM32H7xx STM32H743xx

# board ID. See Tools/AP_Bootloader/board_types.txt
APJ_BOARD_ID 10001

# crystal frequency, setup to use external oscillator
OSCILLATOR_HZ 24000000

FLASH_SIZE_KB 2048

# bootloader takes first sector
FLASH_RESERVE_START_KB 128

# ChibiOS system timer
STM32_ST_USE_TIMER 12
define CH_CFG_ST_RESOLUTION 16

# USB
PA11 OTG_FS_DM OTG1
PA12 OTG_FS_DP OTG1

# SPI1 for IMU (BMI270)
PA5 SPI1_SCK SPI1
PB4 SPI1_MISO SPI1
PD7 SPI1_MOSI SPI1
PC4 BMI270_CS CS

# SPI2 for Barometer (BMP388)
PB13 SPI2_SCK SPI2
PC2 SPI2_MISO SPI2
PC1 SPI2_MOSI SPI2
PC3 BMP388_CS CS

# SPI 4
# PE2 SPI4_SCK SPI4
# PE5 SPI4_MISO SPI4
# PE6 SPI4_MOSI SPI4
# PE4 SPI4_CS CS

# two I2C bus
I2C_ORDER I2C2 I2C1

# I2C1
PB8 I2C1_SCL I2C1
PB7 I2C1_SDA I2C1

# I2C2
PB10 I2C2_SCL I2C2
PB11 I2C2_SDA I2C2

# ADC
PA6 BATT_VOLTAGE_SENS ADC1 SCALE(1)
PA4 DAC ADC1 SCALE(1)

define HAL_BATT_MONITOR_DEFAULT 3
define HAL_BATT_VOLT_PIN 3
define HAL_BATT_VOLT_SCALE 11.0

# LED
PE14 LED1 OUTPUT HIGH GPIO(90) # SYS
PE12 LED2 OUTPUT HIGH GPIO(91) # ERR
PE10 LED3 OUTPUT HIGH GPIO(92) # GPS

define HAL_GPIO_A_LED_PIN 90
define HAL_GPIO_B_LED_PIN 91
define HAL_GPIO_C_LED_PIN 92

define HAL_GPIO_LED_ON 1
define AP_NOTIFY_GPIO_LED_2_ENABLED 1

# order of UARTs (and USB)
SERIAL_ORDER OTG1 USART1 USART2 USART3 UART4 USART6

# USART1
PB14 USART1_TX USART1
PB15 USART1_RX USART1

# USART2
PD5 USART2_TX USART2
PD6 USART2_RX USART2

# USART3
PD8 USART3_TX USART3
PD9 USART3_RX USART3

# UART4
PA0 UART4_TX UART4
PA1 UART4_RX UART4

# USART6
PC6 USART6_TX USART6
PC7 USART6_RX USART6

# Serial functions
# define DEFAULT_SERIAL1_PROTOCOL SerialProtocol_RCIN
# define DEFAULT_SERIAL2_PROTOCOL SerialProtocol_MSP_DisplayPort
# define DEFAULT_SERIAL2_BAUD 115
define DEFAULT_SERIAL3_PROTOCOL SerialProtocol_GPS
# define DEFAULT_SERIAL4_PROTOCOL -1
# define DEFAULT_SERIAL5_PROTOCOL -1

# CAN bus
PD0 CAN1_RX CAN1
PD1 CAN1_TX CAN1

# Motors
PA15  TIM2_CH1  TIM2  PWM(1)  GPIO(50)
PB3  TIM2_CH2  TIM2  PWM(2)  GPIO(51)
PA2  TIM2_CH3  TIM2  PWM(3)  GPIO(52)
PA3  TIM2_CH4  TIM2  PWM(4)  GPIO(53)
PD12 TIM4_CH1 TIM4 PWM(5) GPIO(54)
PD13 TIM4_CH2 TIM4 PWM(6) GPIO(55)
PD14 TIM4_CH3 TIM4 PWM(7) GPIO(56)
PD15 TIM4_CH4 TIM4 PWM(8) GPIO(57)

# Beeper
PA7 TIM3_CH2 TIM3 GPIO(32) ALARM

# microSD support
PC8 SDMMC1_D0 SDMMC1
PC9 SDMMC1_D1 SDMMC1
PC10 SDMMC1_D2 SDMMC1
PC11 SDMMC1_D3 SDMMC1
PC12 SDMMC1_CK SDMMC1
PD2 SDMMC1_CMD SDMMC1

DMA_PRIORITY S*

define HAL_STORAGE_SIZE 32768

# use last 2 pages for flash storage
# H743 has 16 pages of 128k each
STORAGE_FLASH_PAGE 14

# spi devices
SPIDEV bmi270  SPI1 DEVID1 BMI270_CS      MODE3  2*MHZ 10*MHZ
SPIDEV bmp388  SPI2 DEVID1 BMP388_CS      MODE3  2*MHZ 10*MHZ

DMA_NOSHARE SPI1* SPI2*

# Initialize drivers
IMU BMI270 SPI:bmi270 ROTATION_NONE
BARO BMP388 SPI:bmp388

# no built-in compass, but probe the i2c bus for all possible
# external compass types
define ALLOW_ARM_NO_COMPASS
define AP_COMPASS_PROBING_ENABLED 1
define HAL_I2C_INTERNAL_MASK 0
define HAL_COMPASS_AUTO_ROT_DEFAULT 2

# Remove or comment this out if there is no physical SD card slot
define HAL_OS_FATFS_IO 1

# Enable OSD core library, but default it to OFF
define OSD_ENABLED 1
define HAL_OSD_TYPE_DEFAULT 0

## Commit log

2026-08-20 wrote drivers for bmi270 IMU
2026-08-20 Wrote drivers for radio
2026-08-20 added imu and radio to main.c
2026-08-20 added general pid loop function
2026-08-20 implemented motor power mixer
2026-08-21 driver for D-Shot
2026-08-22 updated PID loop to include a LPF, K value instead of P, and derivatives based on the acutal value and not prev error
2026-08-24 board stackup images
2026-08-28 edited radio DMA
2026-09-01 motors DMA and PID tuning
2026-09-01 Code now uses both tim2 and 4 b/c faulty tim2 ch2 and flipped forward and reverse
    [FC.ioc, dshot.c, main.c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]
2026-09-02 editied motor documentation for firmware
2026-09-05 tuned PID

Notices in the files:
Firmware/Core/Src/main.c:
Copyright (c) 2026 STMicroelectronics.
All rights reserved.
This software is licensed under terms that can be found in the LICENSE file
